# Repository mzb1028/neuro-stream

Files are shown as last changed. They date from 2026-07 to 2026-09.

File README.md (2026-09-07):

# Neuro-Stream

**One machine. Ten ingredients. Every drink exact.**

Neuro-Stream is a countertop smart-cartridge dispenser for functional powders
and liquid formulas. It builds a personalized drink in about a minute: it
meters up to **4 ingredients per serving to ±2%** accuracy, dissolves them
in-line in water heated to **±2 °F**, and cleans itself overnight.

**Engineering program: complete — all 6 phases founder-signed (2026-07-10),
plus a buildable MVP pack (wiring, plumbing, part list, build order).**

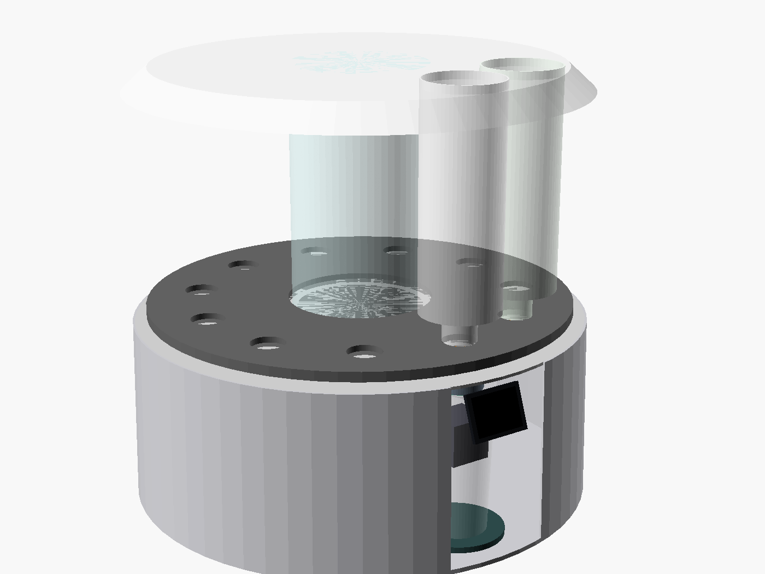
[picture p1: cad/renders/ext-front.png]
Neuro-Stream hero render


## How it works, in one paragraph

Eleven 1-liter smart cartridges (10 ingredients + 1 self-cleaning cartridge)
sit on a rotating carousel around a central removable ~3.5 L water tank. Each
cartridge contains its own factory-calibrated metering mechanism — a dosing
screw for powders, a piston pump for liquids in sterile no-preservative
bags — driven by a single shared motor through a standard docking interface.
Doses drop into a swirling stream of precisely heated water (a venturi
manifold with an off-center water inlet that spins the flow) and dissolve
in-line on the way to the glass. A built-in scale verifies every dose, an NFC
reader identifies each cartridge and loads its calibration, and an ESP32-S3
runs the touchscreen, app, auto-reorder, and wearable-driven recipe
suggestions — all fully usable with no phone present.

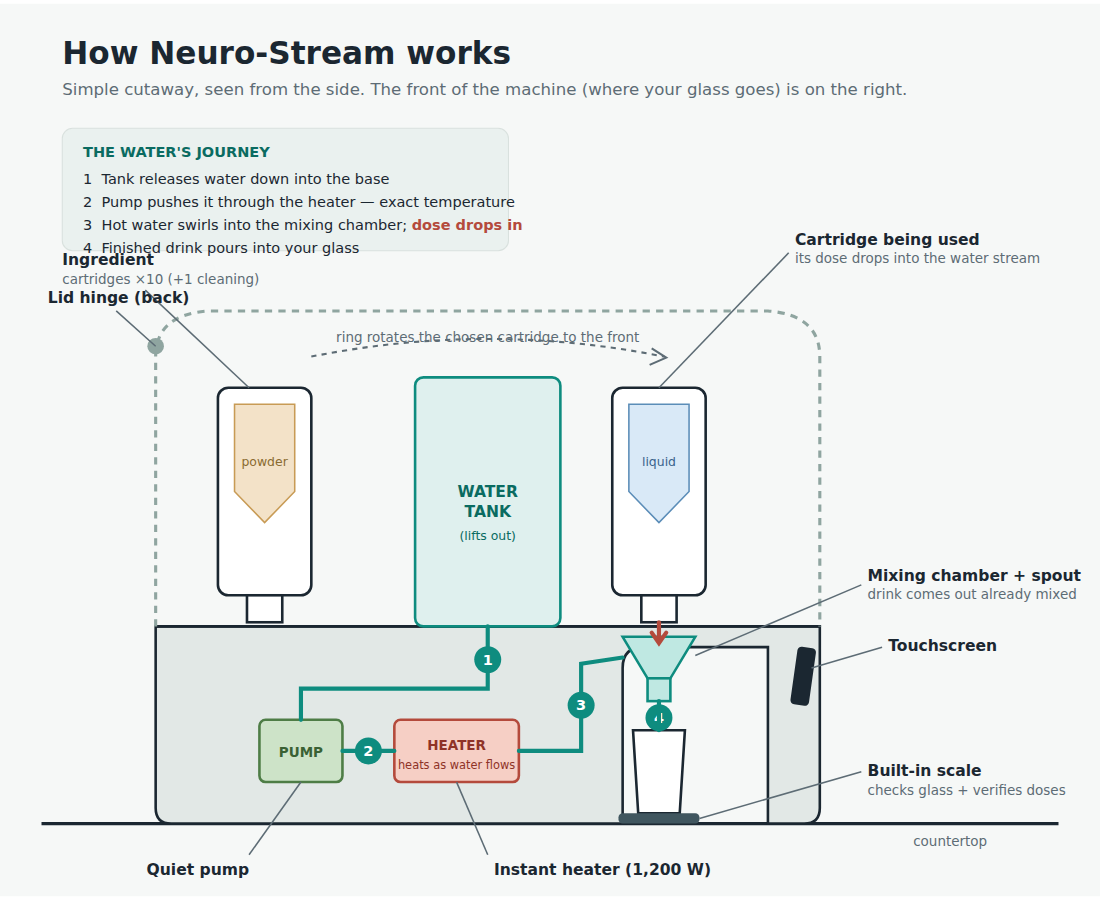
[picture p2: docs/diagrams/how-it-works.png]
How Neuro-Stream works — plain-language cutaway


## Key specs

| Spec | Value |
|---|---|
| Cartridge slots | 11 (10 ingredients + 1 cleaning) |
| Ingredients per drink | up to 4 |
| Dose accuracy | ±2% (scale-verified) |
| Water temperature | ±2 °F, per-recipe setpoint |
| Water tank | ~3.5 L, removable |
| Footprint | Ø 47 cm countertop |
| Controller | ESP32-S3, offline-first; app/NFC/wearables optional |
| Target retail | $499–549 at 5,000-unit production |

## Repository map

### Engineering documents (read in order)

| # | File | Contents |
|---|---|---|
| 1 | [docs/phase1-concept-and-mechanisms.md](docs/phase1-concept-and-mechanisms.md) | Mechanism trade study, dose envelope, architecture decision |
| 2 | [docs/phase2-cad.md](docs/phase2-cad.md) | Parametric CAD guide, tolerances, water/heating amendment |
| 3 | [docs/phase3-electronics-firmware.md](docs/phase3-electronics-firmware.md) | MCU, firmware design, thermal control, connected-product spec |
| 4 | [docs/phase4-materials-food-safety.md](docs/phase4-materials-food-safety.md) | FDA food-contact materials, certifications, self-cleaning model |
| 5 | [docs/phase5-manufacturing-dfm.md](docs/phase5-manufacturing-dfm.md) | DFM, tooling, costs from MVP ($55–105k) to 10k units ($139/unit) |
| 6 | [docs/phase6-validation-testing.md](docs/phase6-validation-testing.md) | Dosing/stability test protocols, certification checklist, stage gates |
| — | [docs/design-metering-venturi.md](docs/design-metering-venturi.md) | Deep dive: cartridge metering internals and wet-wall swirl manifold, with bench test plan |
| — | [docs/mvp-build-spec.md](docs/mvp-build-spec.md) | **Buildable MVP**: shopping list (~$700 electronics + ~$450 printed parts), ESP32 pin map, 4-stage build order, pass/fail tests |
| — | [docs/project-knowledge.md](docs/project-knowledge.md) | **Everything in one file** — self-contained program summary for sharing (Claude Project knowledge, data rooms, onboarding) |

### CAD (OpenSCAD, fully parametric)

| File | Contents |
|---|---|
| [cad/neuro-stream.scad](cad/neuro-stream.scad) | Complete machine: carousel, tank, base, hinged lid, touchscreen. `explode`, `cross_section`, `lid_open`, and `show_*` flags control views |
| [cad/cartridge-metering.scad](cad/cartridge-metering.scad) | Powder cartridge (hopper, sweeper, dosing screw, duckbill seal) and liquid cartridge (leadscrew piston, one-way valves) |
| [cad/venturi-manifold.scad](cad/venturi-manifold.scad) | Swirl mixing cone / venturi manifold |

Every dimension is a named variable. Renders of all views are in
[cad/renders/](cad/renders/).

### Presentation pages

| Where | Contents |
|---|---|
| [Live MVP Build Pack](https://claude.ai/code/artifact/5ff84554-1ebf-416a-b2bb-9e4c18771d7c) | Shareable web version of the build pack (private until shared from its menu) |
| [docs/mvp-build-pack.html](docs/mvp-build-pack.html) | The same page, archived in-repo — open locally in any browser |

### Schematics & diagrams

| File | Contents |
|---|---|
| [docs/diagrams/mvp-wiring.png](docs/diagrams/mvp-wiring.png) | Every wire and ESP32 pin, color-coded by voltage zone, with the full safety chain (GFCI → thermal fuses → relay → hardware watchdog) |
| [docs/diagrams/mvp-plumbing.png](docs/diagrams/mvp-plumbing.png) | Tank → check valve → pump → flow meter → heater → swirl cone, with tube lengths and fittings |
| [docs/diagrams/how-it-works.png](docs/diagrams/how-it-works.png) | Plain-language cutaway of the whole machine |

SVG sources sit next to each PNG.

## The MVP (start here to build)

The MVP in [docs/mvp-build-spec.md](docs/mvp-build-spec.md) is deliberately
**one dispense station with hand-swapped cartridges** — the rotating 11-slot
ring is proven engineering that would only add prototype cost without
reducing risk. The build proves the four claims nobody can prove on paper,
in risk order:

1. **Dry powder dosing** — no water, no mains; proves ±2% by itself
2. **Cold water + swirl cone** — proves in-line dissolution
3. **Smart tags** — NFC cartridge identity and calibration
4. **Heat, last** — only after the full safety chain is wired

Three of the four stages need no mains wiring at all. Every dispense logs a
CSV row; those logs are the evidence file for the beta gate and investors.

## Approved commercialization path

**MVP ($55–105k) → 150-unit beta (~$220k) → 1,000–1,500 soft-mold run →
steel tooling + 5,000-unit production (~$499–549 retail).**

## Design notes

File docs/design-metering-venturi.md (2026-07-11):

# Deep Design: Cartridge Metering Internals & Mixing Manifold

**Models:** [`cad/cartridge-metering.scad`](../cad/cartridge-metering.scad) ·
[`cad/venturi-manifold.scad`](../cad/venturi-manifold.scad)
**Status:** Prototype-ready — these are the two subsystems to build and test
first (they carry the ±2% dosing promise and the "dissolves properly" promise).
**Date:** 2026-07-10

---

## 1. Powder dosing screw — the details that make ±2% real

The screw geometry is easy; **dose consistency** is the design problem. Four
features do the work:

1. **Three confined flights.** The metering zone holds 3 full screw turns
   inside a tight barrel (Ø16 bore, molded to ±0.05 mm). Powder in this zone
   is fully enclosed — only the state of the last flight varies from serving
   to serving, so variance stays small even when the powder itself varies.
2. **Agitator sweeps the barrel entry at constant height.** Two arms turn
   with the screw, 2 mm above the entry slot, keeping it flooded with powder
   at constant pressure ("constant head") from a full cartridge to a nearly
   empty one. This is the anti-drift feature — without it, dose/rev falls as
   the powder column above gets lighter.
3. **60° hopper cone.** Steeper than any target powder's angle of repose plus
   margin → mass flow, no rat-holes, no dead powder at end of life
   (target residual <2% of fill).
4. **Suck-back finish.** At end of dose, firmware reverses the screw ½ turn to
   decompress the last flight, then the silicone duckbill closes. No dribble,
   no dose tail.

**The numbers:** ~1.09 cm³/rev → ~0.65 g/rev at 0.6 g/cm³ bulk density;
motor resolution 0.65 mg/step; 5 g serving ≈ 7.7 rev ≈ 5 s. Torque worst-case
(caked cohesive powder) ≈ 0.12 N·m vs. 2 N·m available — 16× margin, and the
drive current limit doubles as the jam detector.

**Accuracy budget (why ±2% closes):** bore molding ±0.05 mm → ±0.6% volume;
fill-fraction serving-to-serving σ ≈ 0.5–0.8% with the agitator (literature +
to be confirmed on rig); lash <0.1%; balance-verified calibration removes the
mean. Root-sum-square ≈ ±1.2–1.6% (3σ) — inside spec with margin.

## 2. Syrup piston pump — the risky bit is re-priming, not dosing

Dosing is geometric and boring (that's good): Ø20 bore × 4 mm lead = 1.26
mL/rev; bore tolerance ±0.05 mm → ±0.5% volume. The engineering risk is
**refilling the bore with 20,000 cP syrup** between strokes:

- Doses >12.6 mL need multiple strokes: dispense → retract (inlet umbrella
  valve opens, collapsible bag feeds the bore) → dispense again.
- Worst case (cold, thickest syrup): refill through the Ø8 inlet takes 4–7 s
  per stroke. Firmware paces retract speed using the viscosity class from the
  cartridge tag. A 30 mL thick-syrup serving ≈ 40–50 s — acceptable, but
  **this is the number the prototype must confirm.** Fallback knobs: Ø10
  inlet, dual inlet ports, or a lightly spring-loaded bag shell.
- Anti-drip: outlet duckbill needs 0.15 bar to open (holds the column), and a
  ¼-turn reverse decompresses the bore at end of dose.
- Piston seal: silicone X-ring (quad-ring) — lower friction than an O-ring,
  runs dry against a polished POM bore, no lubricant anywhere in the product path.

## 3. Mixing manifold — an honest design evolution

Testing the physics on paper changed the concept, and you should know why:
at our flow rate (~0.5 L/min) a classic venturi generates only ~100–400 Pa of
suction — **too weak to pull powder in reliably.** What works at this scale —
and what fountain and powder-drink machines actually use — is a **wet-wall
swirl cone**, which the model now implements:

- Water enters **tangentially** at the rim and spins into a thin film coating
  the whole cone wall. Powder falls from the cartridge outlet onto this
  *moving* film — every particle lands on water that's already flowing, so it
  wets instantly and can't clump or stick to a dry wall.
- The film converges into a Ø7 **throat** (the venturi-like element) where
  shear finishes dissolution, then a short **mixing tube** (3× throat
  diameter) evens concentration before the spout.
- **Vapor shield:** the subtle killer in hot-water powder systems is steam —
  it rises, condenses in the powder chute, and cakes it shut. A molded baffle
  ring keeps the drop path dry, with a drip edge so condensate returns to the
  swirl, never the chute.
- Still a twist-lock (3-lug bayonet), still the only user-washed part, still
  dishwasher-safe Tritan in production — prototype in clear SLA so you can
  *watch* the film form.

**Tuning knobs left deliberately parametric:** `throat_d` (5–9 mm),
`cone_angle` (50–65°), `inlet_d` (4.5–6 mm). These three get swept on the rig.

## 4. Bench prototype plan (~$2,500 total, 3–4 weeks)

**Rig A — dosing (from cartridge-metering.scad):** printed housings (clear
SLA) + MJF or machined-POM screws, NEMA17 + TMC2209 + ESP32 devkit, 0.001 g
balance. Cartridge hangs neck-down over the balance, exactly like the machine.

| Test | Method | Pass |
|---|---|---|
| Dose repeatability | 50 doses × {1, 5, 15 g} × {creatine, greens, maltodextrin} | σ ≤ 0.8% of dose |
| Life drift | Full-to-empty run, dose every 10th serving weighed | slope flat, all within ±2% of calibrated mean |
| Humidity abuse | Cartridge open at 32 °C/80 %RH for 48 h, then dose | within ±2%, no caking at wiper |
| Suck-back | High-speed video of outlet at dose end | 0 visible dribble |
| Syrup re-prime | 20k cP glycerin blend, cold (15 °C), full-stroke cycling | refill ≤7 s/stroke, dose σ ≤0.5% |
| Jam behavior | Deliberately caked plug | StallGuard trips before spline/screw damage |

**Rig B — mixing (from venturi-manifold.scad):** pump + bench heater + flow
meter into the tangential inlet; Rig A drops powder through the vapor shield.

| Test | Method | Pass |
|---|---|---|
| Film coverage | Dye pulse, clear body | full wet wall <1 s after flow start |
| Dissolution | 5 g greens into 250 mL at 20° and 60 °C; filter, dry, weigh residue | <1% undissolved; no wall cake after 20 servings, no manual clean |
| Steam/caking | 95 °C water 30 s, then powder drop; paper indicator in chute | chute bone dry |
| Carryover | Flavor A → 20 mL rinse → clean water; refractometer + taste | below taste threshold |
| Drip | Valve close, observe spout | ≤2 drops |

**Order of work:** print Rig A parts week 1; dose matrix weeks 2–3; Rig B
sweep (`throat_d` × `cone_angle` × `inlet_d`, ~12 printed variants at ~$18
each) weeks 2–4 in parallel. Every number that passes gets locked into the
main parametric model; every miss has its named fallback above.

These two rigs *are* the heart of the bench MVP from Phase 5 — passing this
plan means the four risky claims are two-thirds proven before the full
machine exists.

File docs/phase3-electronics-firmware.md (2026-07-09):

# Neuro-Stream — Phase 3: Electronics & Firmware

**Status:** Draft for founder sign-off
**Date:** 2026-07-09
**Scope:** dose control, thermal control (±2 °F), calibration, error handling,
power architecture, electronics BOM.

---

## 1. Microcontroller recommendation

**Primary: ESP32-S3-WROOM-1 module (Espressif) — ~$2.60 @ 5k, multi-source
distribution (Digi-Key/Mouser/LCSC), mature toolchain (ESP-IDF).**

Why it wins for this product:

- **Wi-Fi + BLE built in.** A $300–600 wellness appliance with per-user dose
  profiles, recipes, cartridge subscriptions, and OTA firmware updates needs an
  app. On any non-wireless MCU you'd add a radio module and end up paying more.
- **Horsepower headroom:** dual-core 240 MHz — one core owns hard-real-time
  control (steppers, PID, safety), the other runs UI/network. 512 KB SRAM +
  8 MB flash swallows the display UI and OTA A/B partitions.
- Peripherals cover the whole sensor set natively (I²C ×2, SPI, UART, PWM/MCPWM
  for steppers, ADC for NTCs, pulse counter for the flow meter, capacitive touch).
- Supply-chain: ESP32-S3 ships from multiple assembly houses; no allocation
  drama at 10k/yr volumes.

Alternatives considered: **STM32G0B1** (~$1.80) — cheaper, excellent control
MCU, but zero radio: adding BLE/Wi-Fi costs +$2.50–4 and a second firmware
target. **RP2040/RP2350** — nice PIO for steppers, but external flash + radio
still needed. **Nordic nRF52840** — BLE only (no Wi-Fi OTA/cloud), pricier.
Recommendation stands: one ESP32-S3 does everything.

**Safety split:** the 1200 W heater gets an independent hardware safety net
that works even if firmware crashes — two thermal cutoffs (one resettable
klixon, one one-shot fuse) in series with the heater line, plus a watchdog-fed
enable line: the TRIAC can only conduct while the MCU strokes a hardware
watchdog. This is the standard UL-friendly pattern.

## 2. Electronics architecture

```
                 ┌──────────────────────────────────────────────┐
                 │                ESP32-S3 module                │
                 │  core0: control loop (1 kHz)   core1: UI/net  │
                 └──┬─────┬─────┬─────┬─────┬─────┬─────┬───────┘
        TMC2209 ◄───┘     │     │     │     │     │     └──► 2.8" IPS touch (SPI)
      drive stepper   TMC2209   │     │     │     └──► NFC reader PN7150 (I²C)
      (NEMA17 1:5)    carousel  │     │     └──► HX717 load cell ADC
                      stepper   │     └──► flow meter (pulse counter)
                                └──► heater TRIAC (zero-cross, PWM burst)
                                     + 2× NTC (spout, heater body) via ADC
   Power: universal-input 12 V/5 A SMPS board (logic, motors, pump)
          + direct mains leg to heater through TRIAC + dual thermal cutoffs
```

Stepper drivers are **TMC2209**: silent (a kitchen product must not buzz) and
their **StallGuard load measurement is the jam sensor** — no extra hardware.

## 3. Firmware design

### 3.1 Dispense state machine (per recipe of up to 4 ingredients)

```
IDLE → CUP_CHECK → PREHEAT → for each ingredient i (≤4):
        INDEX(i) → DOCK → TAG_VERIFY → CO_DISPENSE(i) → UNDOCK
      → FLUSH → DONE  (any fault → SAFE_STOP → user message)
```

- `CUP_CHECK`: load cell confirms a vessel is present and tares it. No cup,
  no dispense — ever.
- `PREHEAT`: heater brings the loop to set-point ±2 °F before any product
  moves (see 3.3); water recirculates to drain volume is minimal (<15 mL).
- `CO_DISPENSE`: water flows through the venturi *while* the cartridge screw/
  piston meters product into the stream — dissolution happens in-line. Water
  volume per ingredient = recipe water ÷ ingredients, so the last mL of water
  always runs clean (self-rinsing spout).
- `TAG_VERIFY`: NFC tag must authenticate (signed), be in-date, and its
  remaining-dose counter must cover the request. Tag unreadable → **refuse to
  dispense, never guess.**
- `FLUSH`: 20 mL of clean hot water through the venturi at cycle end keeps the
  shared manifold rinsed after every serving.

### 3.2 Dose control (per ingredient)

```c
// dose_g  : target dose from recipe (clamped to tag's max_dose)
// k_cal   : g per drive revolution — read from THIS cartridge's NFC tag,
//           measured on the filling line for this lot (Phase 1, Arch. B)
revs      = dose_g / k_cal;
steps     = revs * STEPS_PER_REV * GEAR_RATIO;        // 0.65 mg/step resolution
run_stepper(DRIVE, steps, profile=TRAPEZOID);
// verification layer (doses ≥ 5 g): compare load-cell delta vs. target
delta = loadcell_delta();
if (dose_g >= 5.0 && fabs(delta - dose_g) > 0.04 * dose_g)   // 2× spec band
    raise(FAULT_DOSE_VERIFY, ingredient);
nfc_decrement_counter(dose_g);                        // update tag bookkeeping
```

### 3.3 Thermal control — hitting ±2 °F (±1.1 °C) at the spout

Classic PID is not enough on a flow-through heater; the loop uses
**feed-forward + PID trim**:

```c
// Feed-forward: power needed to lift measured flow to set-point
//   P_ff [W] = flow [g/s] × 4.186 [J/g°C] × (T_set − T_tank) [°C]
// PID trims the residual using the spout NTC (placed 20 mm after heater exit)
P = P_ff(flow, T_tank, T_set) + PID(T_set − T_spout);
triac_burst_set(P / P_MAX);          // zero-cross burst control, 50/60 Hz safe
```

- Pump runs at constant, flow-meter-verified rate → the feed-forward term is
  accurate, and PID only corrects ±3–4 °F of residual → settles inside ±2 °F
  in <4 s and holds it. This is proven Keurig/espresso-class control.
- **Cup compensation (UX):** optional "temperature at first sip" mode adds a
  model-based offset for vessel heat-steal, calibrated once per cup type.
- Guards: `T_heater_body > 260 °F` → hard fault; flow < 2 g/s while heating
  → boil-dry fault (pump lost prime / tank empty); both independent of the
  hardware cutoffs.

### 3.4 Calibration routines

- **Factory (per cartridge lot):** the fill line dispenses 3 test shots into a
  check-weigher and writes `k_cal` to the tag. The machine itself needs no
  per-cartridge calibration — it inherits it from the tag.
- **Machine self-check (monthly, automatic):** dispense 3 × 10 g water pulses
  by flow meter onto the load cell; cross-compare flow meter, load cell, and
  time. Any pair disagreeing >1.5% flags the drifting sensor and schedules a
  service prompt. This keeps the *verification* chain honest without user labor.
- **Load-cell zero:** auto-tare before every serving; creep-compensated.

### 3.5 Error handling matrix

| Fault | Detection | Response |
|---|---|---|
| Cartridge jam / powder bridge | TMC2209 StallGuard threshold + missed dose on load cell | Reverse ¼ turn ×3 (declog wiggle), retry once; else abort serving, message "Cartridge 4 jammed — remove and shake" |
| Low reservoir (cartridge) | NFC remaining-dose counter + StallGuard running-light signature | Warn at ≤3 servings; refuse when insufficient for recipe |
| Water tank empty | Flow < 2 g/s with pump on | Pause serving, prompt refill, resume (recipe state preserved) |
| Dose verify miss (≥5 g) | Load-cell delta outside ±4% | Abort remaining recipe, flag cartridge, log for QA |
| Overtemp | Spout or body NTC over limit | Firmware kills TRIAC; hardware cutoffs back-stop |
| NFC unreadable/invalid | Auth fail / CRC fail | Refuse that cartridge only; rest of carousel usable |
| Carousel mis-index | Dock cone hall sensor absent after index | Re-home carousel (one full revolution), retry once |
| MCU hang | Hardware watchdog | Heater + motors drop out in <100 ms |

## 4. Battery vs. mains — decided by physics

The 1200 W heater ends this debate: heating 300 mL from 68→140 °F takes
~50 kJ ≈ a **full 18650 cell per drink**. Battery operation would need a
laptop-pack-sized battery per day of use. **v1 is mains-only (universal
100–240 V input).** The only battery aboard is a coin cell for the RTC so
schedules survive unplugging. (A future battery "travel dispenser" would be a
no-heat, dose-only device — different product.)

## 5. Electronics BOM estimate (5k units, mid-2026 pricing)

| Item | Qty | Est. unit cost |
|---|---|---|
| ESP32-S3-WROOM-1 (8 MB) | 1 | $2.60 |
| TMC2209 driver | 2 | $1.40 ea |
| NEMA17 stepper + 1:5 planetary (drive) | 1 | $9.50 |
| NEMA17 pancake stepper (carousel) | 1 | $5.50 |
| Load cell 1 kg + HX717 ADC | 1 | $2.80 |
| NFC reader PN7150 + antenna | 1 | $2.90 |
| 2.8" IPS touch display (SPI) | 1 | $8.00 |
| Diaphragm pump (flow-controlled) | 1 | $8.00 |
| Inline thick-film heater 1200 W | 1 | $14.00 |
| Flow meter (hall) | 1 | $2.50 |
| NTC sensors ×3, thermal cutoffs ×2 | — | $3.20 |
| TRIAC + zero-cross + snubber | 1 | $2.20 |
| 12 V/5 A universal SMPS board | 1 | $6.50 |
| Main PCB (4-layer) + passives + connectors | 1 | $7.50 |
| Wiring harness, dock hall sensor, misc | — | $5.00 |
| **Electronics + electromechanical subtotal** | | **≈ $83** |

(Machine-total BOM including mechanics/enclosure lands in Phase 5; this
subtotal is consistent with a $400–700 retail device at standard multipliers.)

---

**✅ SIGNED OFF by founder (2026-07-09), with amendments:**
1. ESP32-S3 — **approved**, with expanded connected-product requirements (§6)
2. Mains-only — **approved**
3. Error-handling matrix — **approved**, plus offline-first requirement (§6.3)
4. Touchscreen — **approved** (2.8" IPS capacitive)

## 6. AMENDMENT — Connected-product requirements (founder, 2026-07-09)

### 6.1 Auto-reorder
The NFC dose counter already gives per-cartridge remaining servings. Cloud
service adds: low-cartridge event at ≤3 servings → touchscreen + push prompt
("Running low on <name> — reorder?") → one-tap confirm against the stored
subscription. Fully hardware-free; requires the commerce backend (flagged as
a software-team deliverable, not in device BOM).

### 6.2 Wearable integration
Architecture: the **phone app** is the health-data bridge — it reads Apple
HealthKit / Google Health Connect / Garmin / Whoop / Oura APIs and computes
recipe suggestions (e.g., post-run → electrolyte-forward blend, hydration
deficit → larger water volume), which sync to the machine over Wi-Fi/BLE.
The machine itself never talks to wearables directly (no watch vendor allows
third-party devices as direct peers; the phone-bridge is the standard and
correct pattern). No hardware impact; ESP32-S3 BLE also enables direct
phone-to-machine control when offline.

**Regulatory guardrail (carries into Phases 4/6):** health-data-driven dosing
must be presented as *wellness suggestions the user confirms*, never as
automatic therapeutic dosing — otherwise the product risks classification as
a medical device (FDA SaMD). UX copy and marketing must respect this line.

### 6.3 Offline-first (no phone nearby)
The touchscreen is a full-fidelity controller: profiles, saved recipes,
manual dose/temperature/volume, cartridge status, and error recovery all work
with no phone and no internet. Cloud features degrade gracefully (reorder
prompts queue; wearable suggestions simply absent). Firmware rule: **no
dispense path may ever require network round-trips.**

**→ Phase 4: materials & food-safety compliance** (see `docs/phase4-materials-food-safety.md`)

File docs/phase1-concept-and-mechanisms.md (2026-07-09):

# Neuro-Stream — Phase 1: Concept & Mechanism Logic

**Status:** Draft for founder sign-off
**Date:** 2026-07-08

---

## 1. Design inputs (as agreed, with gaps filled by stated assumptions)

| Parameter | Value | Source |
|---|---|---|
| Use context | Consumer countertop, home/on-the-go, zero technical skill | Founder |
| Dosing accuracy | ±2% of target dose per serving | Founder |
| Formula forms | **Both dry powder and liquid**, varying per cartridge | Founder |
| Cartridge count | **Up to 10 independent cartridges**, shipped to user pre-filled | Founder |
| Cartridge capacity | Up to 1 L (or 1 kg-class for powder) each | Founder |
| Dose per serving | Varies by ingredient — see proposed dose envelope (§2) | Founder ("depends") |
| Storage/refrigeration | Unknown — recommendation in §3 | Founder ("advise me") |

> Founder supplied three AI-generated concept renders (rough intent only, not a
> final design). They are reconciled against this phase in **§6**.

### 1.1 What "up to 10 cartridges, powder AND liquid" forces on the design

1. **You cannot afford 10 machine-side precision mechanisms.** Ten motors, ten
   pumps, ten cleanable food-contact paths is a $600+ BOM and a sanitation
   nightmare. Every credible multi-ingredient consumer machine (Keurig,
   Bartesian, Cana) solves this by putting the food-contact complexity in the
   **disposable/replaceable cartridge** and keeping one shared drive in the machine.
2. **Powder and liquid need different metering physics.** No single mechanism
   meters both a cohesive powder and a 5,000 cP syrup at ±2%. The system must
   either (a) run two parallel subsystems, or (b) make the *cartridge* carry the
   media-specific metering element behind a *common mechanical interface*.
3. **±2% across varying particle sizes and viscosities** rules out any open-loop
   mechanism whose delivery-per-actuation depends on the bulk properties of the
   formula — unless each cartridge is factory-calibrated for its specific fill.

## 2. Proposed dose envelope (needs your confirmation)

Since dose "depends on what is being dosed," the machine must be specified
against an envelope. Proposed ingredient classes:

| Class | Form | Dose range | ±2% means | Notes |
|---|---|---|---|---|
| P1 — micro powder | Powder | 0.25–2 g | ±5–40 mg | Concentrated actives (e.g., caffeine blends **pre-diluted in carrier** — see safety note) |
| P2 — standard powder | Powder | 2–15 g | ±40–300 mg | Typical nootropic/greens/creatine-class servings |
| L1 — thin liquid | Liquid | 0.5–10 mL | ±10–200 µL | Tinctures, flavor/active concentrates, ≤ ~500 cP |
| L2 — syrup | Liquid | 5–50 mL | ±0.1–1 mL | Sweetener/functional syrups, up to ~20,000 cP |

**Formula limits the device will impose** (state these to your formulator):

- **Powders:** moisture < 5%, free-flowing to moderately cohesive
  (Carr index ≤ ~25 preferred), particle size D50 ≈ 100–800 µm, oil/fat
  content < ~5% (sticky powders bridge and smear). Hygroscopic powders
  allowed only with desiccant cartridge + wiper-sealed outlet.
- **Liquids:** 1–20,000 cP at 20 °C, no particulates > 0.5 mm, no
  carbonation, must tolerate the cartridge's in-use life at ambient.
- **Safety-by-formulation:** any active where a 2× overdose is harmful must be
  diluted in carrier so that a full-mechanism-fault dose is still safe.
  A consumer device cannot be the sole overdose safeguard.

## 3. Refrigeration & environmental protection — recommendation

**Recommend: design the machine ambient-only and make shelf stability a
formulation/cartridge requirement, not a device feature.**

- Onboard refrigeration (thermoelectric or compressor) adds roughly $40–80 BOM,
  ~2–4 L of enclosure volume, continuous 30–60 W draw (kills any battery
  option), condensation management inside a powder machine (bad), and drives
  you toward compressor reliability/warranty issues. Cana's cooled multi-liquid
  machine ended up at a ~$500–900 price point partly for this reason.
- Instead, protect the formula **in the cartridge**:
  - **Powder cartridges:** integrated desiccant chamber, foil induction seal
    pierced at install, elastomer wiper seal on the outlet so ambient humidity
    can't wick up the dispense path between doses.
  - **Liquid cartridges:** collapsible inner bag (bag-in-shell) so no air
    headspace forms as it empties — this addresses oxidation without nitrogen
    hardware; opaque shell handles light sensitivity.
  - **In-use life** (time from install to empty) becomes a cartridge spec, e.g.
    30–60 days at 15–30 °C / ≤ 60% RH. Your formulator validates each formula
    against it (Phase 6 has the test protocol).
- If a future formula genuinely requires cold chain, that becomes a v2 chilled
  bay variant — don't tax every unit for it.

---

## 4. Three mechanism architectures

### Architecture A — Machine-side dedicated mechanisms per media type
*(bank of mini-augers for powder slots + peristaltic pumps for liquid slots)*

Cartridges are dumb containers; the machine owns all metering. Powder slots get
a stainless auger + agitator each; liquid slots get a peristaltic pump each
(tubing is the only food-contact pump part). A slot is factory-configured or
user-configured as powder or liquid.

**Dosing accuracy path:** auger dose = flights × fill fraction; step-count the
motor. Fill fraction varies with powder cohesion, humidity, and fill level →
open-loop auger accuracy is realistically ±3–8% for varying powders; hitting
±2% requires per-formula calibration *and* stable powder properties, or weight
feedback. Peristaltic is ±1–2% when tubing is fresh but drifts 5–10% as tubing
takes compression set over weeks.

**Pros for your formula set**
- Handles both media with proven, well-understood mechanisms.
- Cartridges are cheap dumb bottles → lowest recurring cost per fill.
- Peristaltic keeps liquid inside disposable tubing — decent hygiene story for liquids.

**Cons**
- **10 mechanisms:** even with clever clutching, this is the highest machine BOM
  and part count of the three.
- Powder path (auger, chute) is machine-side food contact → user must
  disassemble and wash 10 metering assemblies; cross-contamination between
  refills; allergen carryover risk.
- Auger accuracy on *varying* powders won't reliably hit ±2% open-loop.
- Peristaltic tubing is a wear item the consumer must replace on schedule.

**Rough part count / complexity:** ~10 motors (or 1–2 motors + 10-way clutch,
which is its own complexity), ~25–35 parts per powder slot, ~15–20 per liquid
slot → **300+ parts total**, high.

**Food-contact materials:** 316/304 SS or acetal (POM) augers, PP/Tritan
hoppers, platinum-cured silicone peristaltic tubing (all 21 CFR 177-coverable —
detail in Phase 4).

**Failure modes:** powder bridging/rat-holing in hoppers; auger clogging with
hygroscopic caking; peristaltic tube fatigue → drift then rupture; humidity
ingress into open machine-side powder path; cleaning non-compliance by users
(the biggest real-world failure).

---

### Architecture B — Smart cartridges with integrated positive-displacement
metering + one shared machine drive **(recommended)**

Each cartridge contains its own media-matched metering element behind a
**standardized drive interface** (a spline/dog-clutch socket in the cartridge
base). The machine has **one** drive motor that reaches each cartridge —
either the cartridges sit on a rotating carousel over a fixed drive/dispense
station, or a small gantry carries the drive head across a fixed cartridge rack
(decided in Phase 2 against your sketch).

- **Powder cartridge:** molded auger/dosing-screw integral to the cartridge,
  with a slow agitator flight above it (same shaft), foil seal, outlet wiper.
- **Thin-liquid cartridge:** miniature piston/diaphragm dosing element or
  rotary dosing valve, fed by the collapsible bag.
- **Syrup cartridge:** progressive-cavity or larger-bore piston element (the
  interface torque budget is sized for worst-case viscosity).
- Each cartridge carries an **NFC/QR tag** with: ingredient ID, lot,
  **factory-measured calibration constant (g or mL per drive revolution for
  that exact fill lot)**, max dose per serving, expiry, doses-dispensed counter.

**Dosing accuracy path:** positive displacement + per-lot factory calibration
removes the "properties vary" problem — the calibration constant is measured
*with the actual formula in the actual cartridge design* at fill time. Motor
step-counting delivers the dose. Because the metering element is **new with
every cartridge**, wear-related drift resets every ~1 L. Expected: ±2–3%
open-loop; ±2% is met by (a) tightening cartridge molding tolerances on the
metering chamber, and (b) the gravimetric trim described in §5. Fill-level
dependence is handled by the agitator (powder) and collapsed bag (liquid).

**Pros**
- **One motor, near-zero machine-side food contact.** The user never cleans a
  metering mechanism — they recycle it with the cartridge. This is the only
  architecture where "no technical knowledge required" survives contact with
  10 ingredients.
- Cross-contamination and allergen carryover structurally eliminated (each
  formula's entire wetted path is its own cartridge; only the last ~10 mm of
  drop path is shared and is a removable, dishwasher-safe funnel).
- Powder vs. liquid is solved per-cartridge-SKU, invisible to the machine.
- Per-lot calibration is a genuinely strong accuracy story for a formula whose
  particle size and viscosity vary batch to batch.
- Business model alignment: cartridges are already being shipped to users.

**Cons**
- Cartridge unit cost carries the mechanism: roughly **$0.40–1.20 added COGS
  per cartridge** at volume (molded auger or piston element + seals + tag).
- Requires real injection-mold tooling investment for 2–3 cartridge variants
  before revenue (mitigate: launch with powder + one liquid variant).
- Filling line must include a calibration/check-weigh station.
- Drive interface (spline + docking) needs careful tolerance work — it's the
  one precision machine-side part.

**Rough part count / complexity:** machine ≈ **60–90 parts** (1 drive motor +
gearbox, carousel or gantry with 1–2 cheap positioning motors, load cell,
electronics, enclosure); cartridge ≈ 6–9 parts each (shell, bag or agitator,
metering element, seals, foil, tag, cap). Medium overall — complexity is
shifted into high-volume molded disposables, which is where manufacturing is
cheapest.

**Food-contact materials:** cartridge shell PP or PET, metering screw/piston
POM or PP, seals platinum-cured silicone or TPE, bag PE/EVOH laminate — all
mainstream 21 CFR 177 materials (Phase 4).

**Failure modes:** powder caking if user stores machine in high humidity
(mitigated by desiccant + wiper seal); mold-to-mold variation in metering
chamber volume (mitigated by per-lot calibration, which absorbs it); drive
spline wear (machine side, hard-anodized or SS, 10k-cycle rated); counterfeit
or refilled cartridges dosing wrongly (mitigated by signed NFC tags); tag
read failure (fail-safe: refuse to dispense, never guess).

---

### Architecture C — Gravimetric closed-loop
*(crude dispense mechanisms + precision load cell; accuracy from measurement,
not metering)*

Any cheap dispense method (coarse auger, pinch valve on gravity-fed liquid)
runs in closed loop against a load cell under the user's glass: dispense fast
to ~90% of target, then pulse in dribble mode until the scale reads the target.

**Dosing accuracy path:** accuracy = scale accuracy. A consumer-grade load
cell + 24-bit ADC (HX711-class) realistically holds ±0.1 g in a kitchen
environment (vibration, thermal drift, someone bumping the counter).
**±2% is therefore only achievable for doses ≥ ~5 g.** Class P1 (0.25–2 g)
and L1 low-end (0.5 mL) fail the spec outright. Liquids also drip/string after
cutoff, corrupting the endpoint.

**Pros**
- Totally agnostic to formula changes — no per-lot calibration, self-corrects
  bridging and partial clogs, inherently detects jams and empty cartridges.
- Cheapest cartridges of the three (dumb containers).
- The load cell doubles as a UX feature ("add 200 mL water… done").

**Cons**
- **Cannot meet ±2% below ~5 g** → fails your micro-dose classes.
- Slow: dribble-mode endpoint approach adds 5–20 s per ingredient × up to 10
  ingredients per drink.
- Requires the user's vessel on the scale, correctly placed, undisturbed —
  fragile against exactly the "no technical knowledge" user you're targeting.
- Still needs 10 crude dispensers with machine-side food contact (Architecture
  A's cleaning problem returns, just with cheaper mechanisms).

**Rough part count / complexity:** ~200+ parts (10 crude dispensers + scale
station). Medium-high.

**Food-contact & failure modes:** as Architecture A for the dispense path;
plus load-cell drift, tare errors, vibration sensitivity, drip-after-cutoff.

---

## 5. Recommendation: Architecture B, with a load cell as a verification layer

**Primary metering: cartridge-integrated positive displacement (B).
Secondary: a load cell under the dispense station used not for control but for
*verification and drift/jam detection* on doses ≥ ~5 g (a de-contented C).**

Justification against the alternatives:

1. **Only B meets ±2% across the whole dose envelope.** C's physics caps it at
   ~5 g minimum. A's open-loop auger can't hold ±2% on powders whose particle
   size and cohesion vary — and your formula characteristics explicitly vary.
   B converts that variability from a machine problem into a fill-line
   calibration measurement, which is where you can actually control it.
2. **Only B survives the consumer-simplicity requirement at 10 ingredients.**
   A and C both leave 10 food-contact metering paths in the machine that a
   non-technical user must clean correctly, repeatedly, forever. Field data
   from every appliance category says they won't. B's user-facing sanitation
   burden is one dishwasher-safe drop funnel.
3. **Cost lands in the right place.** A puts ~$300+ of mechanisms in a machine
   you sell once (probably at a loss). B puts ~$1 of mechanism in a cartridge
   you sell every month — and injection-molded disposables at volume are the
   cheapest precision parts in existence.
4. **The load-cell layer buys back C's best property cheaply** (~$4 of BOM):
   every ≥5 g dose is check-weighed, so the machine detects clogs, exhausted
   cartridges, and calibration drift, logs accuracy for QA/regulatory
   evidence, and can flag "cartridge underdelivering — replace" instead of
   silently mis-dosing. Small doses rely on positive displacement + factory
   calibration alone, which is exactly where positive displacement is
   strongest.

**Cost of this choice, stated plainly:** upfront cartridge tooling
(~$80–250k across 2–3 cartridge variants before launch) and recurring
cartridge COGS. If that capital doesn't exist, the fallback is Architecture A
reduced to **3–4 slots** with a relaxed accuracy spec (±5%) on powders — but
that is a different product. Recommendation stands on B.

### Carry-forward decisions for Phase 2 (CAD)

- Carousel vs. gantry cartridge presentation — **decide against your sketch**
  (please attach it with your sign-off).
- Standard drive interface geometry (spline profile, docking float, torque cap).
- Cartridge variant set for launch: P2 powder + L2 syrup first; P1/L1 second.
- Shared drop-funnel geometry and its removal/cleaning gesture.

---

## 6. Reconciliation with founder's concept renders

The three renders (Gemini-generated, directional only) show:

1. **An under-counter, plumbed, pull-out-drawer appliance** integrated into
   cabinetry, with a dedicated counter-top tap/faucet, inline water-filter
   housings, and a touch control panel.
2. **Cartridges as inverted metal bottles** (6–8 visible) docked mouth-down in
   a drawer rack, with labels like "Sparkling Water / Cold Brew / Cucumber
   Lime / Still Water."
3. **A 12-position rack of small flavor pucks** plus what appears to be a
   **CO₂ cylinder** and filter canisters.

**What this confirms about Phase 1:**

- The fixed **rack + drawer** layout in the renders settles the carousel vs.
  gantry question in favor of **fixed cartridge rack** — either a traveling
  drive head (gantry) or, better for a drawer, **one small drive/valve module
  per docking station fed by a single shared controller** re-evaluated in
  Phase 2 against cost.
- Inverted bottle-style cartridges docking mouth-down onto a station is
  exactly Architecture B's smart-cartridge docking concept. The metering
  element lives in the bottle's neck/cap assembly.
- 10–12 positions matches the agreed "up to 10" envelope.

**What this changes / adds (scope decisions needed):**

| Render feature | Implication | Decision needed |
|---|---|---|
| Plumbed water line + tap | This is a **point-of-use water dispenser that doses formula into the water stream**, not a device dosing into an arbitrary glass. Dispense path becomes an inline injection manifold; the "drop funnel" becomes a tap spout. Installation now involves a plumber or a tank-fed fallback. | In or out for v1? Plumbed-in roughly doubles regulatory surface (NSF/ANSI 42/53/61 for the water path) and kills "on-the-go." |
| Under-counter drawer form factor | Sheet-metal chassis + drawer slides instead of a molded countertop enclosure; changes Phase 2 CAD entirely. Conflicts with the stated "countertop, on-the-go" use context. | Countertop v1 with the same cartridge/docking system, drawer version as v2? (Recommended — the cartridge platform is the asset; the enclosure can vary.) |
| CO₂ cylinder / sparkling | Carbonation module: regulator, carbonator, certified cylinder handling. Big, well-understood, but a product in itself. | Recommend **out of v1**; the docking rack design will not preclude adding it later. |
| Chilled water ("Cold Brew," temperature display) | Water chilling is different from formula refrigeration (§3 stands: cartridges stay ambient). A thermoelectric water chiller is feasible in a plumbed v2. | Defer with plumbing decision. |
| Metal bottle cartridges | Aluminum bottles are premium-looking but fight Architecture B: molded metering elements, NFC tags, and collapsible liners integrate far more cheaply into a **molded PP/PET shell** (which can be metallized or sleeved for the same look). | Treat metal look as industrial design finish, not construction. |

**Recommended v1 scope, restated:** countertop enclosure, 10-position fixed
rack of smart cartridges (Architecture B), doses into the user's own glass/
bottle of water via a short shared spout, load-cell verification underneath.
Plumbing, carbonation, and water chilling are v2 features the docking
architecture deliberately leaves room for.

---

**✅ SIGNED OFF by founder (2026-07-09), with amendments:**
1. Architecture B (+ load-cell verification) — **approved**
2. Dose envelope classes P1/P2/L1/L2 (§2) — **approved** (clarified: these are
   per-serving dispense ranges, not cartridge sizes; cartridges remain 1 L)
3. Ambient-only storage — **approved with condition: all ingredients are
   preservative-free.** Consequences adopted:
   - Powders: unaffected (dry + desiccant + foil seal is sufficient).
   - Liquids: **sterile-fill into a collapsible aseptic bag with a one-way
     check valve** is the mandatory packaging standard. In-use life per
     formula must be validated in Phase 6; thin aqueous liquids may carry a
     shorter machine-enforced expiry (read from the cartridge tag).
4. Launch cartridge set P2 powder + L2 syrup — **approved**
5. v1 scope (countertop, dose-into-glass; plumbed drawer = v2) — **approved**

**Added requirement (founder, 2026-07-09):** one serving may combine **up to
4 ingredients** (any mix of powders and liquids). Implemented as sequential
dispensing of up to 4 cartridges into the shared funnel per recipe. Whether
the machine also *stirs* the finished drink is flagged as an open industrial-
design decision in the Phase 2 document (recommendation: user stirs in v1).

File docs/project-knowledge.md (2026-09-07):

# Neuro-Stream — Complete Project Knowledge File

*Self-contained summary of the entire engineering program. Drop this file into
any workspace (Claude Project, Notion, investor data room) and the reader has
the whole picture. Full detail lives in the repo:
https://github.com/mzb1028/neuro-stream — status as of 2026-09-07.*

---

## 1. What Neuro-Stream is

A countertop smart-cartridge dispenser for functional powders and liquid
formulas. It builds a personalized drink in about a minute: meters up to
**4 ingredients per serving to ±2%** accuracy, dissolves them in-line in
water heated to **±2 °F** of the recipe setpoint, verifies every dose on a
built-in scale, and cleans itself overnight.

**Program status: complete.** All six engineering phases founder-signed
(final sign-off 2026-07-10), plus a hands-on MVP build pack (wiring,
plumbing, parts list, build order) added afterward.

### Key specs

| Spec | Value |
|---|---|
| Cartridge slots | 11 (10 ingredients + 1 self-cleaning cartridge) |
| Cartridge capacity | 1 L / ~1 kg-class each, shipped pre-filled |
| Ingredients per drink | up to 4 |
| Dose accuracy | ±2%, factory-calibrated per cartridge, scale-verified |
| Water temperature | ±2 °F (±1.1 °C) at the spout, per-recipe setpoint |
| Water tank | ~3.5 L, removable |
| Footprint | Ø 47 cm countertop |
| Controller | ESP32-S3; Wi-Fi/BLE, NFC, touchscreen; fully offline-capable |
| Power | Mains (1200 W inline heater rules out battery) |
| Target retail | $499–549 at 5,000-unit production |

## 2. The architecture (Phase 1 decision)

Three architectures were traded off:

- **A — machine-side mechanisms per media type**: rejected ($600+ BOM, 10
  cleanable food paths, sanitation nightmare).
- **B — smart cartridges with integrated positive displacement** ✅ chosen:
  each cartridge carries its own media-specific metering element (dosing
  screw for powders, piston pump for liquids in sterile no-preservative
  bag-in-box) behind a common docking interface, driven by ONE shared machine
  motor. Factory calibration per cartridge, stored on its NFC tag.
- **C — gravimetric closed-loop**: kept as a *verification* layer only — a
  load cell under the glass checks every dose rather than controlling it.

Why: no single mechanism meters both cohesive powder and 5,000 cP syrup to
±2%; putting food-contact complexity in the replaceable cartridge (the
Keurig/Bartesian/Cana pattern) keeps the machine clean and cheap.

**Dose envelope** the machine is specified against: P1 micro powders
0.25–2 g, P2 standard powders 2–15 g, L1 thin liquids 0.5–10 mL (≤500 cP),
L2 syrups 5–50 mL (≤20,000 cP). Concentrated actives must be pre-diluted in
carrier by the formulator.

## 3. Mechanical design (Phases 2 + deep dive)

- **Layout**: 11 cartridges on a rotating carousel around a central removable
  water tank; hinged clear lid; front dispense bay with touchscreen; drive
  motor, pump, heater, and PCBA in the base.
- **Powder cartridge internals**: hopper cone with rotating sweeper arms
  (prevents bridging/rat-holing), precision dosing screw, silicone duckbill
  outlet seal. Delivery is per-revolution, calibrated at fill time.
- **Liquid cartridge internals**: leadscrew-driven piston pulling from an
  aseptic bag (no preservatives needed), one-way valves; the engineering risk
  is re-priming after idle, not dosing.
- **Mixing**: doses drop dry into a venturi/swirl manifold; heated water
  enters the cone **tangentially (off-center)** so it spins — a straight-in
  inlet dribbles down one wall and clumps powder. Dissolution happens in the
  stream, not in the glass.
- **CAD**: fully parametric OpenSCAD — `cad/neuro-stream.scad` (whole
  machine, with `explode`/`cross_section`/`lid_open` flags),
  `cad/cartridge-metering.scad`, `cad/venturi-manifold.scad`. 20+ renders in
  `cad/renders/`.
- **One precision metal part**: the drive spline shaft, CNC 316L stainless
  (corrected from 303 during the materials review), ~$3.80/pc.

## 4. Electronics & firmware (Phase 3)

- **MCU**: ESP32-S3 (Wi-Fi + BLE on module). Drives: 2× stepper (TMC2209
  with StallGuard jam detection — cartridge drive + carousel), 12 V
  diaphragm pump (MOSFET), 1200 W inline heater via zero-cross SSR, flow
  meter, 2× NTC (spout tee + heater body), 1 kg load cell + HX717, PN532
  NFC at the dock collar, 2.8" IPS SPI touchscreen, hall/reed position
  switches.
- **Dispense state machine**: identify cartridge (NFC) → rotate to dock →
  dose (steps from stored calibration) → scale verification → next
  ingredient → heat/mix water pass → done. Error matrix covers jams
  (StallGuard), empty cartridge, no glass, boil-dry.
- **Thermal control**: feed-forward + PI on the spout NTC hits ±2 °F;
  firmware boil-dry guard (flow < 2 g/s → heater off) plus hardware chain:
  GFCI → 2 thermal cutoffs in series → SSR → hardware watchdog that kills
  heat if firmware hangs.
- **Connected product (founder amendment)**: auto-reorder from cartridge
  fill-level telemetry; wearable integration drives recipe *suggestions*
  (wellness framing, not medical); **offline-first** — every function works
  with no phone present.
- Electronics BOM ≈ $83/unit at 5k volume.

## 5. Materials & food safety (Phase 4)

- Cartridge wetted parts: Tritan shells, POM screw/piston, platinum-cured
  LSR seals/valves, aseptic PE bag — all FDA food-contact grades with
  supplier letters collected into an FDA food-contact file.
- Machine water path: Tritan tank and manifold, silicone tube, 316L wetted
  heater.
- **Self-cleaning model (founder-approved)**: slot 11 holds a cleaning
  cartridge; machine runs an overnight rinse/sanitize cycle through the
  full wet path. Design requirement: no dead legs, all wetted surfaces
  flushable.
- Certifications flagged: UL/ETL 60335-2-15 (mandatory — it heats water),
  FCC (module-based), FDA food-contact file, NSF/ANSI 42 (voluntary),
  CA Prop 65, 21 CFR 111 cGMP filling via co-packer.

## 6. Manufacturing & cost (Phase 5)

**Tooling (Asia)**: machine ≈ $180–225k, cartridges ≈ $117k → **program
total ≈ $300–340k** one-time (1.7–2× if tooled in the US). This is the
capital gate.

**Machine build cost / suggested retail** (±15% estimate grade):

| Year-1 volume | Build cost | Landed (+12%) | Retail (≈3×) |
|---|---|---|---|
| 2,000 | ≈ $188 | ≈ $211 | $599–649 |
| 5,000 | ≈ $158 | ≈ $177 | **$499–549** |
| 10,000 | ≈ $139 | ≈ $156 | $449–479 |

**Small batches (100–1,500 units)** skip steel tools: MJF/SLS-printed or
CNC enclosures at 100–500 units, soft aluminum molds at 500–1,500. The one
exception: **cartridge food-contact parts can never be 3D printed** — soft
cartridge molds (~$50–65k) are unavoidable even for a 100-unit pilot.
Aseptic bags come from a bag-in-box supplier (MOQ ~50k).

**Approved commercialization path**:
MVP ($55–105k) → 150-unit beta (~$220k) → 1,000–1,500 soft-mold run →
steel tooling + 5,000-unit production run.

## 7. Validation & certification (Phase 6)

- **Dosing protocol**: full-to-empty cartridge runs on the bench MVP,
  repeated on every design change; every dispense logs a CSV row — the logs
  are the evidence file for the beta gate and investors.
- **Temperature protocol**: spout-thermocouple verification across
  setpoints and tank temperatures.
- **150-unit beta adds** real-world variation: homes, water hardness, user
  abuse, formula stability in the machine.
- **Formula stability**: accelerated studies during beta, real-time before
  retail ($8–15k per formula).
- **Certification budget through retail: ≈ $90–150k** (UL $25–40k, FCC
  $5–10k, FDA file $8–15k, NSF $10–20k, legal reviews, product-liability
  insurance ~$15–30k/yr — required before even beta loaners ship).
- Stage gates: MVP must pass bench dosing + temperature before beta; beta
  must pass stability + formal certs before soft-mold run.

## 8. The MVP (buildable today)

Deliberately **one dispense station with hand-swapped cartridges** — the
rotating ring is proven engineering that adds prototype cost without
reducing risk. ~$1,150 in parts (~$700 electronics/hardware + ~$450 printed
parts), ~2 weekends of assembly.

Build order, risk-first:
1. **Dry powder dosing** — no water, no mains; alone proves ±2%
2. **Cold water + swirl cone** — proves in-line dissolution
3. **Smart tags** — NFC identity + calibration
4. **Heat, last** — only after the full hardware safety chain is wired

Three of four stages need no mains wiring; a pre-built inline heater or an
appliance tech can cover the fourth. Full parts list, ESP32 pin map,
assembly order, firmware starting points, and pass/fail criteria:
`docs/mvp-build-spec.md`. Every-wire schematic and every-tube plumbing
diagram: `docs/diagrams/mvp-wiring.png`, `docs/diagrams/mvp-plumbing.png`.

## 9. Where everything lives

| Asset | Location |
|---|---|
| Repository (single source of truth) | https://github.com/mzb1028/neuro-stream |
| Phase docs 1–6 | `docs/phase1…phase6…*.md` |
| Metering/venturi deep dive | `docs/design-metering-venturi.md` |
| MVP build spec | `docs/mvp-build-spec.md` |
| Parametric CAD (OpenSCAD) | `cad/*.scad`, renders in `cad/renders/` |
| Schematics & diagrams | `docs/diagrams/` (SVG sources + PNG) |
| MVP Build Pack web page | live: https://claude.ai/code/artifact/5ff84554-1ebf-416a-b2bb-9e4c18771d7c · archived: `docs/mvp-build-pack.html` |

## 10. Open items / watch list

- Founder to confirm the dose envelope holds for the launch formula set.
- Highest cost/delay risks (Phase 5): the ≥650-tonne press for the Ø47 cm
  carousel ring (few vendors — quote early), aseptic bag MOQ, UL timeline
  (3–4 months — start pre-review on polished prototypes).
- Wellness-claims legal review required before the app ships
  wearable-driven suggestions.

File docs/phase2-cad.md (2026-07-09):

# Neuro-Stream — Phase 2: Parametric CAD Model

**Status:** Draft for founder sign-off
**Date:** 2026-07-09
**Model:** [`cad/neuro-stream.scad`](../cad/neuro-stream.scad) (OpenSCAD 2021.01+)
**Renders:** [`cad/renders/`](../cad/renders/)

---

## 1. Layout decision: carousel, not drawer rack (for v1)

Phase 1 left the cartridge-presentation question open. Decided: **rotating
carousel** for the countertop v1.

- 10 × Ø80 mm cartridges in a straight rack (as in your renders) makes a
  ~950 mm-wide machine — a drawer works under a counter, not on one.
- A carousel packs the same 10 stations into a **Ø~440 mm, ~465 mm tall**
  cylinder — large-blender footprint.
- It needs only **one docking/drive station**: the carousel rotates the chosen
  cartridge over it. One drive motor + one cheap indexing motor serve all 10
  stations, which is the whole point of Architecture B.
- Your 4-ingredient recipe requirement is sequential: index → dock → dispense,
  four times. At ~5–16 s per ingredient plus ~1.5 s indexing, a 4-ingredient
  serving takes **~30–60 s**.
- The v2 under-counter drawer keeps the identical cartridge and docking-cone
  interface — only the presentation mechanism changes.

## 2. What's in the model

Open `cad/neuro-stream.scad`. Every dimension is a named variable at the top;
the geometry re-derives when you change them. Highlights:

| Variable | Value | What it controls |
|---|---|---|
| `n_stations` | 10 | Cartridge count — set 6 and the whole machine shrinks into a compact SKU |
| `cart_od` / `cart_h` | 80 / 220 | Cartridge envelope (≈1 L net) |
| `spline_d`, `spline_clr` | 10, 0.15 | The standard drive interface and its fit |
| `aug_*` | 16/8/8 | Powder dosing screw → ≈0.65 g/rev |
| `pist_id`, `pist_lead` | 20, 4 | Syrup piston pump → ≈1.26 mL/rev |
| `explode` | 0–1 | Exploded-view slider |
| `cross_section` | bool | Half-section through internals |

**View controls:** `explode=1` for the exploded assembly, `cross_section=true`
for a half-section, `show_*` flags to isolate subsystems. Render from CLI:

```
openscad -o out.png --imgsize=1200,900 --camera=0,0,230,65,0,35,1500 \
         -D explode=1 cad/neuro-stream.scad
```

## 3. Key tolerances and why (also commented in the model)

| Feature | Tolerance | Rationale |
|---|---|---|
| Spline socket↔shaft | 0.15 mm diametral | Absorbs POM molding variation (±0.05 mm typ.) + carousel positioning error while keeping rotational backlash <2°, so step-count dose error from lash stays <0.1% of one revolution |
| Docking cone seat | +0.2 mm on neck | Slip fit that still centres the outlet within ±0.3 mm over a 12 mm funnel throat |
| Carousel station bore | +0.4 mm on neck | Deliberately loose drop-in fit — a consumer must never have to aim; precision location comes from the cone, not the plate |
| Docking capture range | ±2.5 mm | Cone mouth vs. neck: the indexing motor + molded ring gear only need to be this accurate, so no precision gearing anywhere |
| Cartridge shell wall | 1.6 mm PP | PP flow-length sweet spot: <1.2 mm short-shots on a 220 mm part, >2.5 mm sinks and adds cycle time |
| Metering chamber (screw OD/bore) | ±0.05 mm (mold spec, SPI A-2 cavity) | Chamber volume variation is the largest open-loop dose error source; ±0.05 on Ø16 ≈ ±0.6% volume, leaving budget inside ±2% — and per-lot fill-line calibration absorbs the systematic part |

## 4. Dose math sanity check (±2% feasibility)

- **Powder (P2):** 0.65 g/rev; NEMA17 at 200 steps/rev through 1:5 gearing →
  0.65 mg per full step. A 5 g dose = ~7.7 rev = 5 s at 90 rpm. Quantization
  error is negligible; accuracy is governed by fill-fraction repeatability,
  which the agitator + per-lot calibration constant handle.
- **Syrup (L2):** 1.26 mL/rev → 30 mL ≈ 24 rev ≈ 16 s. Check-valve pair
  re-primes the piston from the aseptic bag; the one-way valve means no air
  ever back-fills the bag (founder's preservative-free requirement).
- **Micro-dose (P1, later):** same architecture with a smaller screw
  (`aug_barrel_id=8, aug_pitch=4` → ~0.08 g/rev, 1.25 rev minimum dose).

## 5. Part → manufacturing process map

### Machine (sellable unit)

| Part | Qty | Process | Notes |
|---|---|---|---|
| Chassis skirt + tower shells | 2 | **Injection mold** (ABS) | Largest tools in the program; texture spec MT-11010 |
| Internal deck plate | 1 | **Sheet metal** (1.5 mm galv.) | Flat + stiff + cheap at launch volume; convert to a 3rd molding above ~20k units/yr |
| Carousel plate w/ molded ring gear | 1 | **Injection mold** (30% GF-PP) | Molded gear is fine — cone does final location |
| Docking cone | 1 | **Injection mold** (GF-PP) | |
| Drive spline shaft (annular crown) | 1 | **CNC** (316L SS — Phase 4 correction) | The one precision machined part; product falls through its centre, torque enters around it |
| Drop funnel | 1 | **Injection mold** (Tritan) | Only user-washed food-contact part; twist-lock, dishwasher-safe |
| Weigh platform / drip tray | 2 | **Injection mold** (ABS / PP) | |
| Lid | 1 | **Injection mold** (clear PC) | |
| Drive stepper + 1:5 planetary | 1 | **OTS** | NEMA17 class |
| Carousel index stepper + pinion | 1 | **OTS** | |
| Carousel bearing (slew ring) | 1 | **OTS** | Lazy-susan class, not precision |
| Load cell 1 kg + mounts | 1 | **OTS** | TAL221 class |
| Lift cam, spring, small hardware | — | **OTS** | |
| NFC reader module | 1 | **OTS** | Reads cartridge tag at dock |

### Powder cartridge (P2) — 7 parts, all high-volume

| Part | Process |
|---|---|
| Shell + integral neck | Injection mold, PP (food-contact grade) |
| Dosing screw + agitator (one part) | Injection mold, POM |
| Outlet wiper/duckbill seal | LSR micro-mold |
| Foil induction seal | OTS converting |
| Desiccant puck | OTS |
| NFC tag inlay | OTS |
| Snap base cap | Injection mold, PP |

### Syrup cartridge (L2) — 8 parts

| Part | Process |
|---|---|
| Shell | Injection mold, PP |
| Piston pump block + leadscrew (2 pts) | Injection mold, POM |
| Inlet + outlet check valves (2 pts) | LSR micro-mold |
| Aseptic collapsible bag + one-way valve | OTS (bag-in-box industry standard, sterile-filled) |
| NFC tag inlay | OTS |

## 6. Open items flagged for founder

1. **Stirring/dissolution:** the machine dispenses up to 4 ingredients into the
   glass but does not stir. Powders like greens blends need agitation to
   dissolve. Options: (a) user stirs — recommended for v1, zero cost;
   (b) magnetic stirrer coil under the weigh platform + a puck in a branded
   shaker cup (~$6 BOM); (c) defer to v2. **Recommendation: (a), with (b) as a
   fast-follow accessory.**
2. **Compact SKU:** `n_stations=6` yields a Ø~350 mm machine from the same
   parts. Worth deciding before tooling, since the carousel tool would differ.
3. This is a **concept-geometry model** — correct architecture, envelopes,
   interfaces, and tolerances for review. Production surfacing (ribs, bosses,
   draft angles, snap details) belongs in a mechanical-CAD package (Fusion/
   SolidWorks) during Phase 5 DFM; the .scad stays the dimensional source of
   truth until then.

---

## 7. AMENDMENT — Water / heating / mixing subsystem (founder-approved 2026-07-09)

Founder decision: v1 must dissolve powders and incorporate liquids properly,
and must deliver water at a user-set temperature within **±2 °F**. Scope
change adopted: v1 gains a **tank-fed hot-water system with in-stream venturi
mixing** (this supersedes the "user stirs" recommendation in §6.1).

**Architecture** (now in the parametric model, `show_water=true`):

- **Removable ~3.5 L Tritan tank in the dead centre of the carousel ring** —
  the carousel is rim-driven, so its middle is empty; the tank lives there and
  lifts out through the lid. Machine footprint is unchanged.
- Water path: tank → poppet coupling → diaphragm pump → hall flow meter →
  **1200 W inline thick-film heater** (PID against outlet NTC + measured
  flow) → tangential inlet of the **venturi/swirl mixing manifold** mounted
  under the docking cone. Dosed ingredients drop from the cartridge outlet
  directly into the swirling heated stream and dissolve in-line before the
  spout. The manifold replaces the drop funnel as the single user-removable,
  dishwasher-safe food-contact part.
- **±2 °F at spout** is a firmware deliverable (Phase 3 PID + feed-forward on
  flow); heater-only system heats from tank temperature up to ~205 °F —
  chilling remains a v2 feature.
- Consequences accepted: mains-only power (1200 W kills battery), UL
  heating-appliance certification path (+$15–30k, +2–3 months), NSF/ANSI 42
  attention on the water path, descaling routine, added BOM ~$30–45.

**Sign-off status:** carousel layout, 10-station envelope, and Ø80×220
cartridge confirmed by founder ("go forward", 2026-07-09) together with this
subsystem. Mixing decision resolved: **venturi in-stream mixing** (no stirrer).

---

**→ Phase 3: electronics & firmware** (see `docs/phase3-electronics-firmware.md`)

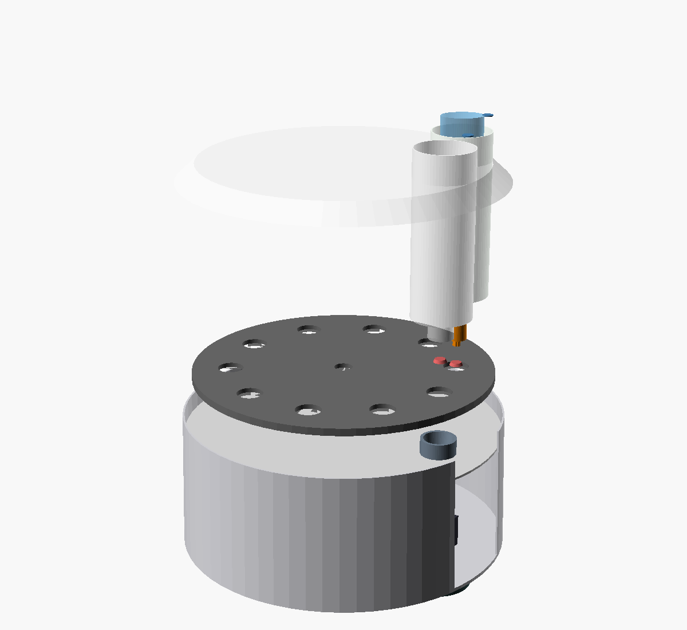
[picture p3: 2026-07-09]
cad/renders/exploded.png

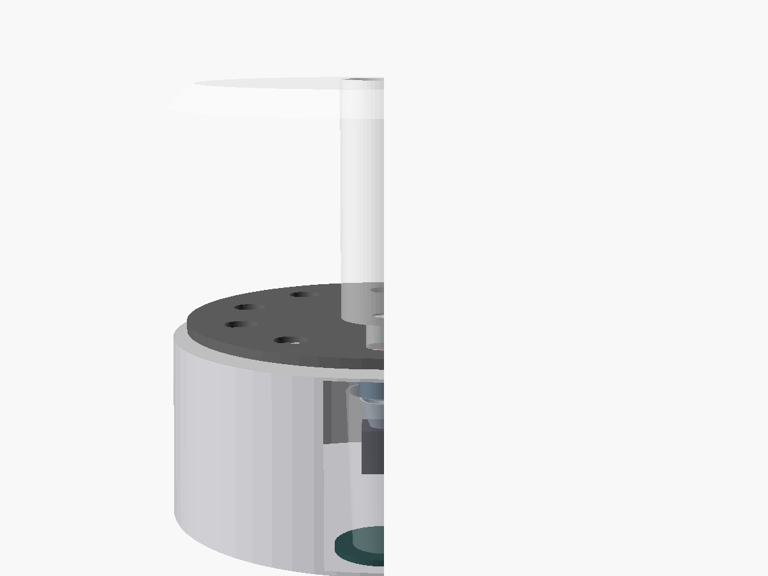
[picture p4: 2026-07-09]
cad/renders/section.png

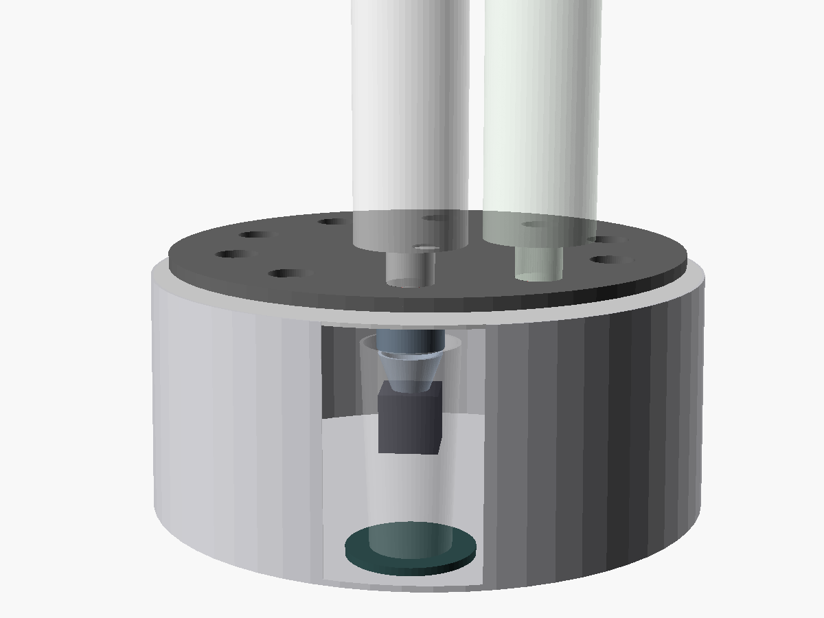
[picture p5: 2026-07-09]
cad/renders/front-bay.png

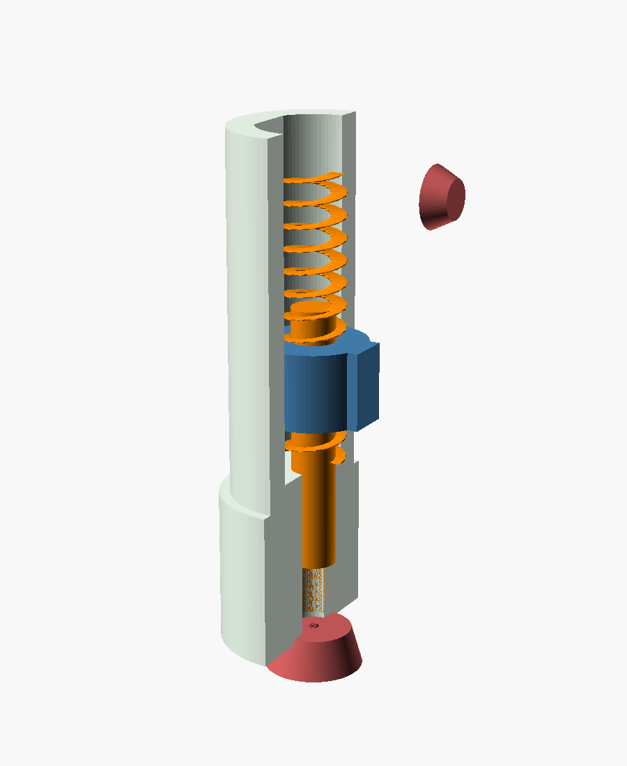
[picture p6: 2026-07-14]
cad/renders/cart-syrup.png

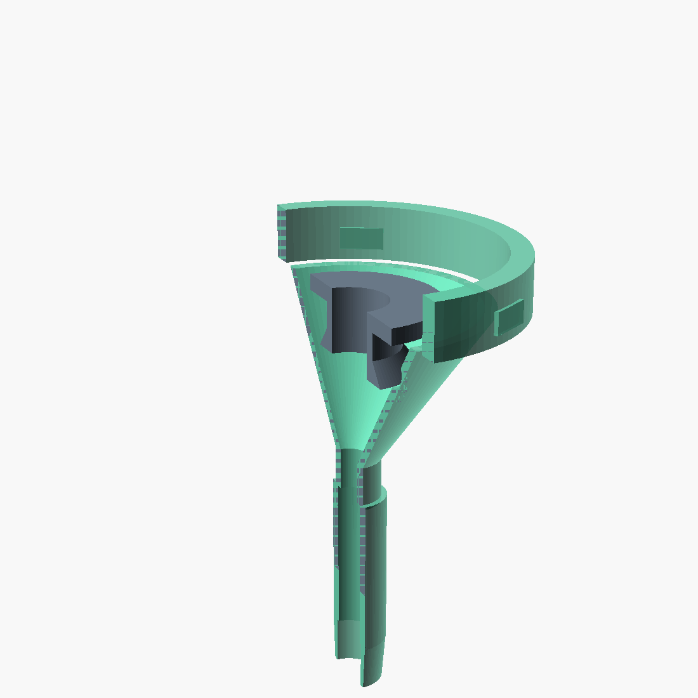
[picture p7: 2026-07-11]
cad/renders/venturi-detail.png

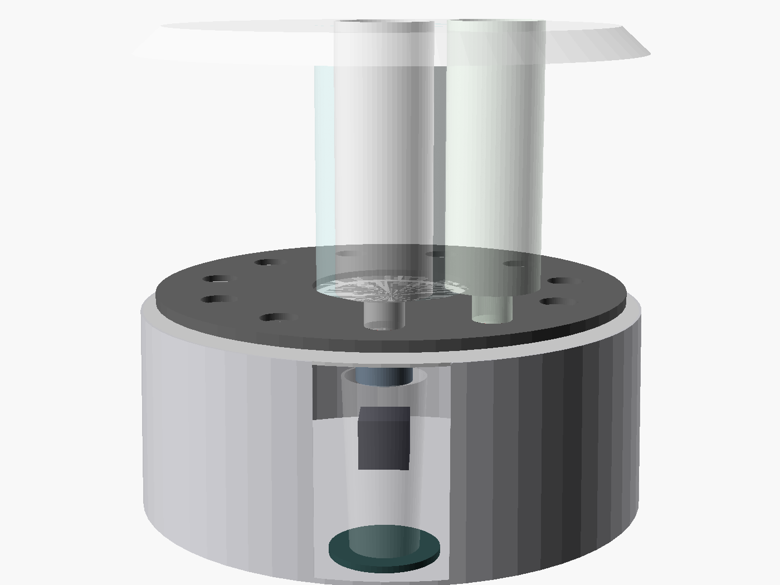
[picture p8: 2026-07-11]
cad/renders/v-front.png

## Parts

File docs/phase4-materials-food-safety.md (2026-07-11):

# Neuro-Stream — Phase 4: Materials & Food-Safety Compliance

**Status:** Draft for founder sign-off
**Date:** 2026-07-09
**Scope:** food-contact material selection per part (FDA 21 CFR 177),
certification flags, cleaning/sanitation requirements.

> Not legal advice: final compliance sign-off belongs with a food-contact
> regulatory consultant before tooling kickoff. This phase specifies materials
> with clear regulatory pathways so that review is a formality, not a redesign.

---

## 1. Formula-contact and water-contact parts, material by material

### 1.1 Cartridge (formula contact — the critical set)

| Part | Material | FDA pathway | Notes |
|---|---|---|---|
| Shell + neck | Polypropylene (homopolymer, food grade) | **21 CFR 177.1520** (olefin polymers) | Choose a resin with supplier FCS letter of guarantee; natural (unpigmented) inner surface |
| Dosing screw / piston block, leadscrew | Acetal (POM) copolymer | **21 CFR 177.2470** | Standard for food-machinery gears/screws; low friction, no lubricant needed (any grease in the product path must be NSF H1, but the design needs none) |
| Outlet wiper / duckbill / check valves | Platinum-cured LSR silicone | **21 CFR 177.2600** (rubber articles, repeated use) | Platinum-cure only — peroxide-cured silicone leaves volatiles; verify extractables per 177.2600 (e) |
| Aseptic collapsible bag | PE sealant / EVOH barrier laminate | PE: **177.1520**; EVOH: **177.1360** | Standard aseptic bag-in-box stack; buy as a converted component from an aseptic-bag supplier with existing FDA compliance docs |
| One-way bag valve | PE/silicone | as above | OTS from same bag supplier |
| Foil induction seal | Alu/PE lamination | **177.1520** + GRAS aluminum | Industry standard |
| Desiccant puck (powder SKU) | Silica gel in Tyvek/PE housing | Indirect contact; use FDA-grade dessicant pack | OTS (Multisorb-class) |
| NFC tag inlay | — | **No product contact** — bonded to shell exterior | Keep it outside; zero compliance burden |

### 1.2 Machine water path (water contact)

| Part | Material | Pathway | Notes |
|---|---|---|---|
| Water tank | Eastman Tritan copolyester | FDA-cleared via Eastman FCNs | BPA-free story is also a marketing asset; dishwasher-safe |
| Tank poppet coupling | PP + EPDM O-ring | 177.1520 / 177.2600 | EPDM must be potable-water grade |
| Pump (wetted path) | Buy **food/potable-grade pump** (PP/EPDM wetted) | Supplier declaration | Spec at sourcing time — many diaphragm pumps are not potable-rated |
| Water tubing | Platinum-cured silicone | 177.2600 | High-temp rated (post-heater segment sees ~96 °C) |
| Inline heater wetted surface | 316L stainless steel | GRAS / accepted food-contact metal | Thick-film heaters with 316L flow tubes are standard coffee-machine parts |
| Flow meter body | PP/POM potable-rated | 177.1520 / 177.2470 | OTS potable-rated part |
| Venturi mixing manifold + spout | Tritan | Eastman FCNs | The one user-washed part; must survive 1000+ dishwasher cycles |

### 1.3 Machine parts near, but not touching, product

Docking cone (GF-PP), carousel (GF-PP), chassis (ABS), lid (PC): **no direct
product contact by design** — the cartridge's own outlet passes through the
cone and delivers into the venturi. Keeping these out of the food-contact set
is deliberate: glass-filled and flame-retardant grades are hard to clear for
contact, and this design never needs to.

### 1.4 One correction from Phase 2

The spline drive shaft was drafted as **303 stainless** (free-machining).
303's sulfur content makes it a poor food-adjacent choice; although the shaft
is nominally non-contact (annular, around the outlet), powder dust will settle
on it. **Changed to 316L, machined.** Cost delta ≈ +$0.40/unit. The .scad
comment will be updated when the model is next touched.

## 2. Certification & testing flags

| Requirement | Applies to | When |
|---|---|---|
| **UL/ETL 60335-2-15** (household water-heating appliances) | Whole machine (heater!) | Mandatory for US retail; the heater moved us from the simple motor-appliance category into this one. Budget $25–40k, 3–4 months, engage the lab at EVT stage |
| **FCC Part 15 + intentional radiator** | ESP32-S3 Wi-Fi/BLE | Use the module's existing modular certification to cut cost/time; still need end-product verification |
| **NSF/ANSI 42** (or NSF/ANSI 51 materials listing) | Water path | Not legally mandatory for a consumer countertop unit, but retailers (Costco/Williams-Sonoma/Amazon brand registry) increasingly ask; the materials above are chosen to pass without change |
| **FDA food-contact compliance file** | All §1 parts | Assemble Letters of Guarantee from every resin/component supplier pre-tooling; consultant review ≈ $8–15k |
| **CA Prop 65** | Whole product | Verify no listed substances (mind brass fittings — use none) |
| **Cartridge filling operation** | Your fill line / co-packer | This is the big one outside the device: filling ingestible cartridges is **dietary-supplement manufacturing under 21 CFR 111 cGMP** — FDA-registered facility, lot traceability, stability data. Choose a co-packer who already holds this; do not build it yourself for launch |
| Wellness-claims guardrail | App + marketing | Health-data-driven dosing stays "suggestions" (see Phase 3 §6.2) or FDA SaMD risk attaches |

## 3. Cleaning & sanitation design requirements

> **SUPERSEDED in part by §5 (founder-approved self-cleaning model,
> 2026-07-09).** The design rules at the end of this section still apply;
> the user-facing regimen table is replaced by §5.

The design's core sanitation argument: **every formula's wetted path is
disposable** (lives in the cartridge, replaced ~monthly), and the shared path
is exactly two things — the venturi manifold and the spout.

Resulting user-facing regimen (this becomes manual + app copy):

| Task | Frequency | How |
|---|---|---|
| Venturi manifold + spout | Weekly (or on ingredient-class change) | Twist off, top-rack dishwasher. Machine reminds via screen; interlock detects it missing and refuses to dispense |
| Self-rinse | Every serving | Automatic 20 mL hot flush (firmware, Phase 3) — this is why weekly (not daily) manual washing is defensible |
| Water tank | Weekly | Rinse; dishwasher-safe monthly |
| Drip tray / weigh platform | Weekly | Sink or dishwasher |
| Descale cycle | Every 3 months (hardness-adjusted) | Citric-acid cycle, screen-guided, ~15 min; firmware tracks liters-since-descale |
| Deep water-path sanitize | Every 6 months | Dilute NaOCl or percarbonate cycle + double rinse, screen-guided |
| Docking cone wipe | Monthly | Damp cloth; no disassembly |

Design rules locked by this phase:
- No shared surface that a *formula* touches except venturi + spout (both
  user-removable, dishwasher-safe, transparent so soiling is visible).
- No crevices <1 mm radius in any wetted molded part (mold spec).
- All wetted materials rated ≥ 100 °C (hot flush + dishwasher + descale chemistry).
- Silicone water lines replaceable as a service part without tools beyond a
  Phillips screwdriver (10-year serviceability posture).

---

## 5. AMENDMENT — Self-cleaning model (founder-approved 2026-07-09)

Founder requirement: **the user should never have to clean the machine.**
Adopted design:

- **11 carousel slots** (was 10): 10 ingredient cartridges + **1 dedicated
  slot for a cleaning cartridge**. Machine grows to Ø~47 cm.
- **Cleaning cartridge SKU** (3rd cartridge type): same body/neck/tag as
  ingredient cartridges; two chambers — food-safe detergent/sanitizer
  concentrate + citric-acid descaler. Ships in every subscription box.
  Machine reads the tag, knows when cleaning last ran, and prompts.
- **Overnight self-clean cycle** (~30 min, scheduled by user, runs unattended):
  hot detergent flush of venturi/spout/water path → soak → descale stage when
  needed → triple rinse. Effluent (~1–1.5 L) exits the normal spout into a
  **user-placed container that the load cell verifies is present and large
  enough before the cycle will start**. (Direct sink drain is a v2
  under-counter feature.)
- **Water-tank filter cartridge** (Brita-class, ~$2 BOM + consumable):
  cuts scale, stretches descale interval, improves taste.
- **Conductivity sensor** (~$1 BOM): measures actual water hardness so
  descaling is scheduled by need, not calendar.
- Residual user tasks: place a container the night a clean runs; rinse the
  drip tray occasionally. Everything else is automatic (including the 20 mL
  hot rinse after every serving).
- Firmware additions (annexed to Phase 3 spec): cleaning-cycle state machine,
  container-mass check, hardness-based descale scheduler, cleaning-cartridge
  tag handling, "won't dispense while cleaning-overdue > 2 weeks" nag policy.

---

**✅ SIGN-OFF STATUS (in the simplest terms):**

1. **The plastics and metals list (§1)** — **approved by founder 2026-07-10**
2. **The safety-testing plan and budget (§2, ~$35–55k)** — **approved by
   founder 2026-07-10**
3. **Self-cleaning model (§5)** — **approved by founder 2026-07-09** (11
   slots, cleaning cartridge, overnight cycle, tank filter, hardness sensor)
4. → Phase 5: manufacturing plan and tiered pricing. **Volume path approved
   2026-07-10: MVP → 150-unit beta → scale.**

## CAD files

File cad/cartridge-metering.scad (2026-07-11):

// ============================================================================
// NEURO-STREAM — Cartridge metering internals (deep design, prototype-ready)
// Companion to neuro-stream.scad (machine-level model).
//
// TWO MECHANISMS IN THIS FILE:
//   part = "powder"  → dosing-screw assembly (class P2)
//   part = "syrup"   → piston pump assembly  (class L2)
//   part = "both"    → side by side
//
// PROTOTYPE INTENT: geometry is printable for bench testing —
//   screw/agitator + pump parts: SLS/MJF nylon or machined POM
//   barrels/housings: SLA clear resin (watch the powder/syrup move)
//   seals: cast or bought silicone (see notes)
// Bench tolerances (printed): ±0.2 mm — fine for dose-physics testing.
// Production tolerances (molded): metering bore ±0.05 mm (SPI A-2 cavity).
// ============================================================================

part          = "both";   // "powder" | "syrup" | "both"
explode       = 0;        // 0 assembled … 1 exploded
half_section  = false;    // cut housings to show internals
$fn = 96;

ex = explode;
function exz(mm) = ex*mm;

// ---------------------------------------------------------------------------
// SHARED: neck + 6-lobe spline socket (matches machine drive, spline_d=10)
// ---------------------------------------------------------------------------
neck_od     = 34;
neck_h      = 28;
outlet_d    = 12;
spline_d    = 10;
spline_lobes= 6;
spline_len  = 12;
spline_clr  = 0.15;   // POM socket vs 316L shaft — see machine model rationale

module spline_socket_negative() {   // subtract from driven part
    r = spline_d/2 + spline_clr/2;
    linear_extrude(spline_len+0.5)
        for (i=[0:spline_lobes-1])
            rotate(i*360/spline_lobes) translate([r*0.55,0]) circle(r=r*0.5);
}

// ============================================================================
// POWDER DOSING SCREW  (class P2: 2–15 g servings, target 0.65 g/rev)
// ============================================================================
// DESIGN NOTES (the details that make ±2% real):
//  * Dose/rev = π/4·(D²−d²)·pitch·fill ≈ 1.09 cm³ → ~0.65 g/rev @ 0.6 g/cm³.
//    Fill fraction is the variable — per-lot calibration absorbs its mean;
//    the geometry below controls its VARIANCE:
//  * 3 full flights inside the barrel → powder in the metering zone is fully
//    confined; only the last flight's state varies serving-to-serving.
//  * Agitator arms sweep 2 mm above the barrel entry slot at 1:1 screw speed —
//    keeps the slot flooded (constant head) from full to empty. This is the
//    single most important feature for no-drift-across-cartridge-life.
//  * Hopper cone at 60° from horizontal (steeper than any target powder's
//    angle of repose + 15° margin) → mass flow, no rat-holing.
//  * End-of-dose: firmware reverses 0.5 rev ("suck-back") to decompress the
//    last flight, then the duckbill wiper closes. Kills after-dribble.
//  * Torque budget: cohesive powder shear in this barrel ≈ 0.05–0.12 N·m;
//    spline + POM screw rated 0.5 N·m (4× margin). NEMA17+1:5 delivers 2 N·m.

aug_barrel_id = 16;      // metering bore (THE precision dimension, molded ±0.05)
aug_root_d    = 8;
aug_pitch     = 8;
aug_flight_t  = 2.2;     // flight thickness
aug_turns_in  = 3;       // flights confined in barrel
barrel_wall   = 2.5;
barrel_len    = aug_turns_in*aug_pitch + 6;
entry_slot_w  = 14;      // barrel entry slot (top side, under agitator)
entry_slot_l  = 16;
hopper_angle  = 60;      // deg from horizontal — anti-bridging
hopper_top_d  = 74;      // matches cartridge shell ID
agit_arm_r    = 33;      // agitator sweep radius
agit_clear    = 2;       // arm height above hopper floor

module powder_screw() {
    // one molded/printed part: spline socket + screw + agitator arms
    color("DarkOrange") difference() {
        union() {
            // screw root through barrel + up into hopper
            translate([0,0,-barrel_len]) cylinder(d=aug_root_d, h=barrel_len+8);
            // helical flight (true helix)
            translate([0,0,-barrel_len])
                linear_extrude(barrel_len, twist=-360*barrel_len/aug_pitch,
                               slices=barrel_len*6, convexity=10)
                    translate([(aug_root_d+ (aug_barrel_id-aug_root_d)/2)/2 - aug_root_d/4 + aug_root_d/2 - ((aug_barrel_id-aug_root_d)/4),0])
                        square([(aug_barrel_id-aug_root_d)/2, aug_flight_t], center=true);
            // hub above hopper floor
            translate([0,0,6]) cylinder(d=14, h=8);
            // two agitator arms, swept tips, 2 mm over hopper floor
            for (a=[0,180]) rotate(a)
                translate([0,0,agit_clear+8]) hull() {
                    translate([6,0,0])        sphere(d=6);
                    translate([agit_arm_r,0,10]) sphere(d=6);  // rises along cone
                }
        }
        translate([0,0,-barrel_len-0.4]) spline_socket_negative();
    }
}

module powder_housing() {
    // barrel + hopper cone + neck (cartridge-bottom insert, one molded part)
    color("WhiteSmoke", half_section?1:0.45) difference() {
        union() {
            // neck
            translate([0,0,-neck_h]) cylinder(d=neck_od, h=neck_h);
            // barrel body
            translate([0,0,-barrel_len]) cylinder(d=aug_barrel_id+2*barrel_wall, h=barrel_len);
            // hopper cone
            cylinder(d1=aug_barrel_id+2*barrel_wall, d2=hopper_top_d,
                     h=(hopper_top_d-aug_barrel_id)/2*tan(hopper_angle));
        }
        // metering bore
        translate([0,0,-barrel_len-1]) cylinder(d=aug_barrel_id, h=barrel_len+2);
        // hopper interior
        translate([0,0,0.01])
            cylinder(d1=aug_barrel_id, d2=hopper_top_d-4,
                     h=(hopper_top_d-aug_barrel_id)/2*tan(hopper_angle));
        // entry slot from hopper into barrel top flight
        translate([-entry_slot_l/2,-entry_slot_w/2,-aug_pitch-2])
            cube([entry_slot_l, entry_slot_w, aug_pitch+3]);
        // outlet bore through neck
        translate([0,0,-neck_h-1]) cylinder(d=outlet_d, h=neck_h+2);
        if (half_section) translate([0,-100,-200]) cube([200,200,400]);
    }
}

module duckbill_seal() {
    // LSR duckbill at outlet: powder passes down, humidity blocked upward.
    // Prototype: buy Ø12 silicone duckbill (Minivalve-class); this is a stand-in.
    color("IndianRed") translate([0,0,-neck_h-6-exz(25)]) {
        difference() {
            cylinder(d1=outlet_d+6, d2=outlet_d+2, h=7);
            translate([0,0,-0.5]) cylinder(d1=outlet_d+2, d2=2, h=7.5);
        }
    }
}

module powder_assembly() {
    powder_housing();
    translate([0,0,exz(70)]) powder_screw();
    duckbill_seal();
}

// ============================================================================
// SYRUP PISTON PUMP  (class L2: 5–50 mL servings, 1.26 mL/rev)
// ============================================================================
// DESIGN NOTES:
//  * Rotation→stroke inside the cartridge: spline turns a leadscrew (lead
//    4 mm) engaged in the piston's molded nut; piston is keyed against
//    rotation by two flats in the bore.  1 rev = 4 mm × π·10² = 1.26 mL.
//  * Full stroke 40 mm = 12.6 mL per stroke. Doses >12.6 mL auto-cycle:
//    dispense-stroke → fast retract (re-prime from bag) → repeat.
//  * Re-prime physics (the risky bit for 20,000 cP syrup): retract at
//    ≤6 mm/s with Ø8 inlet → bag pressure (collapsible, ~0.05 bar elastic
//    + atmospheric) refills in 4–7 s worst case. Firmware paces retract
//    speed by syrup viscosity class from the NFC tag. PROTOTYPE MUST VERIFY.
//  * Check valves: inlet umbrella (cracks 0.03 bar, low restriction),
//    outlet duckbill (cracks 0.15 bar — holds column, no drip). End-of-dose
//    reverse ¼ rev decompresses the bore.
//  * Piston seal: single X-ring (quad ring), silicone, Ø20 bore — lower
//    friction than O-ring, no lubricant (dry POM bore, Ra 0.4).
//  * Accuracy: displacement is geometric — bore ±0.05 mm ⇒ ±0.5% volume;
//    leadscrew molded pitch error <0.3%; both absorbed by per-lot k_cal.

pist_bore   = 20;
pist_stroke = 40;
lead        = 4;
pump_od     = 30;
pump_len    = pist_stroke + 26;
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

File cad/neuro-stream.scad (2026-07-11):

// ============================================================================
// NEURO-STREAM v1 — Parametric concept model (Phase 2)
// Countertop 10-station smart-cartridge dispenser, Architecture B
//
// OpenSCAD 2021.01+.  All dimensions in millimetres.
//
// HOW TO USE
//   explode = 0;          assembled view
//   explode = 1;          fully exploded view (parts translate apart)
//   cross_section = true; cut the model in half to see internals
//   show_* flags          isolate subsystems
//
// MANUFACTURING FLAGS (also repeated per-module):
//   [IM]  injection molded        [CNC] machined
//   [SM]  sheet metal             [OTS] off-the-shelf purchased part
//   [EXT] extrusion, cut to length
// ============================================================================

// ---------------------------------------------------------------------------
// VIEW CONTROLS
// ---------------------------------------------------------------------------
explode        = 0;      // 0 = assembled … 1 = fully exploded
cross_section  = false;  // true = half-section through machine centreline
show_chassis   = true;
show_carousel  = true;
show_cartridges= true;   // one powder + one syrup cartridge shown docked
show_drive     = true;
show_dispense  = true;   // funnel, load-cell platform, drip tray
show_lid       = true;
show_water     = true;   // tank, pump, heater, venturi mixing manifold
lid_open       = 0;      // 0 = closed … 75 = flipped open on rear hinge (deg)
show_screen    = true;   // 2.8" touchscreen on the front face

$fn = 64;                // curve resolution (raise for exports)

// ---------------------------------------------------------------------------
// MASTER PARAMETERS — the numbers you will actually tune
// ---------------------------------------------------------------------------

// ---- Cartridge envelope (shared by all cartridge SKUs) --------------------
cart_od          = 80;    // cartridge body outer dia. 80 dia × 220 tall ≈ 1.0 L net
cart_h           = 220;   // cartridge body height (above neck)
cart_wall        = 1.6;   // [IM] PP shell wall. 1.6 mm is the sweet spot for
                          // PP flow length vs. rigidity; <1.2 warps, >2.5 sinks.
cart_neck_od     = 34;    // neck that seats into the docking station
cart_neck_h      = 28;    // neck engagement length
cart_outlet_d    = 12;    // product outlet bore

// ---- Standard drive interface (THE precision interface of the machine) ----
// 6-lobe spline socket molded into every cartridge metering element; mating
// steel spline shaft rises from the drive station.
spline_d         = 10;    // spline major dia
spline_lobes     = 6;
spline_len       = 12;    // axial engagement
spline_clr       = 0.15;  // TOLERANCE: fit clearance between molded POM socket
                          // and machined steel shaft. 0.15 mm absorbs molding
                          // variation (±0.05 typ. for a 10 mm POM feature) plus
                          // carousel positioning error, while keeping rotational
                          // backlash < 2° so step-counted dose error from lash
                          // stays below 0.1% of a 1-revolution dose.
spline_lead_in   = 2;     // chamfer so blind docking self-aligns

// ---- Carousel & station geometry -------------------------------------------
n_stations       = 11;    // FOUNDER-APPROVED 2026-07-09: 11 slots =
                          // 10 ingredient cartridges + 1 dedicated slot for
                          // the self-cleaning cartridge. Set 6 for a compact
                          // SKU — everything below re-derives automatically.
station_gap      = 15;    // clearance between adjacent cartridge bodies
pitch_c          = n_stations * (cart_od + station_gap);   // pitch circumference
pitch_r          = pitch_c / (2 * PI);                     // station pitch radius
carousel_r       = pitch_r + cart_od/2 + 12;               // carousel disc radius
carousel_t       = 6;     // [IM] carousel plate thickness (glass-filled PP)
station_bore     = cart_neck_od + 0.4;  // TOLERANCE: neck-to-plate fit. +0.4 mm
                          // diametral = drop-in fit for a consumer with no
                          // aiming; radial location comes from the tapered
                          // docking cone below, not this bore.

// ---- Chassis ----------------------------------------------------------------
deck_h           = 185;   // carousel deck height above countertop. Must exceed
                          // glass_h + funnel_h + 25 mm clearance.
base_r           = carousel_r + 18;   // chassis skirt radius
base_wall        = 2.5;   // [IM] ABS enclosure wall
glass_h          = 150;   // tallest vessel the dispense bay accepts
bay_w            = 110;   // dispense bay opening width

// ---- Powder metering element (class P2) -------------------------------------
// Vertical dosing screw in the cartridge neck, agitator on the same shaft.
aug_barrel_id    = 16;    // [IM] barrel bore molded into neck insert
aug_root_d       = 8;     // screw root dia
aug_pitch        = 8;     // flight pitch
aug_turns        = 3;     // flights inside the barrel
// dose/rev ≈ π/4·(id²−root²)·pitch·fill ≈ 1.09 cm³/rev ≈ 0.65 g/rev @0.6 g/cm³.
// A 5 g serving ≈ 7.7 rev; at 90 rpm that is a 5 s dispense. Resolution per
// motor full-step (200 steps/rev, 1:5 gear) ≈ 0.65 mg — far inside ±2%.
agitator_r       = cart_od/2 - cart_wall - 4;  // sweep radius of agitator flight

// ---- Syrup metering element (class L2) --------------------------------------
// Piston displacement pump driven through an internal leadscrew from the same
// rotary spline — cartridge converts rotation to linear stroke internally.
pist_id          = 20;    // piston bore
pist_stroke      = 40;    // max stroke per re-prime cycle
pist_lead        = 4;     // leadscrew lead: 4 mm/rev → 1.26 mL/rev.
// 30 mL serving ≈ 24 rev ≈ 16 s at 90 rpm. Check-valve pair re-primes from bag.

// ---- Drive station -----------------------------------------------------------
drive_travel     = 14;    // vertical engage/retract stroke of spline shaft
motor_l          = 42;    // [OTS] NEMA17 stepper + 1:5 planetary
cone_big_d       = cart_neck_od + 6;   // docking cone mouth
cone_small_d     = cart_neck_od + 0.2; // TOLERANCE: cone seat. +0.2 mm on the
                          // neck gives a slip fit that still centres the outlet
                          // over the funnel within ±0.3 mm — powder stream and
                          // syrup drip both land inside a 12 mm funnel throat.

// ---- Dispense bay -------------------------------------------------------------
funnel_top_d     = 46;    // [IM] shared drop funnel, dishwasher-safe, tool-less
funnel_bot_d    = 14;
funnel_h         = 38;
loadcell_l       = 55;    // [OTS] 1 kg single-point load cell (TAL221-class)
platform_d       = 95;    // [IM] weighing platform / drip tray top

// ---- Water / heating / mixing subsystem (founder-approved 2026-07-09) ---------
// Tank lives in the dead space inside the carousel ring: zero footprint cost.
tank_d           = 140;   // [IM] removable tank, Ø140 × 250 ≈ 3.5 L usable
tank_h           = 250;
tank_wall        = 2.0;   // Tritan (clear, tough, dishwasher-safe)
pump_l           = 55;    // [OTS] diaphragm pump body length (base compartment)
heater_l         = 90;    // [OTS] inline thick-film heater, 1200 W
heater_d         = 32;
tube_d           = 8;     // silicone water line, 8 mm OD
// TOLERANCE: tank-to-base water coupling uses a spring poppet + EPDM O-ring;
// coupling bore +0.1/-0 on a Ø14 spigot — sealing comes from the O-ring
// squeeze (25% nominal), not the bore fit, so molding variation is absorbed.
venturi_l        = 34;    // [IM Tritan] mixing manifold: heated water enters
venturi_d        = 22;    //   tangentially, product drops in from the cone
                          //   above, swirl + venturi throat dissolves powder
                          //   in-stream before the spout. Removable for wash.
spout_d          = 10;

// ---- Lid ----------------------------------------------------------------------
lid_h            = 24;    // [IM] hinged translucent lid over cartridge deck

// Exploded-view translation distances (scaled by `explode`)
ex   = explode;
function exz(mm) = ex * mm;   // axial explode helper

// ============================================================================
// PART MODULES
// ============================================================================
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

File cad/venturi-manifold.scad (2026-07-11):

// ============================================================================
// NEURO-STREAM — Mixing manifold deep design (prototype-ready)
//
// HONEST ENGINEERING NOTE (why this is a "swirl wetting cone", and the pure
// venturi idea evolved): at our pump flow (~0.5 L/min = 8.3 mL/s) water
// velocities are ~0.3–0.9 m/s — venturi suction at that speed is only
// ~100–400 Pa: too weak to *entrain* powder reliably. What actually works at
// this scale (and is how commercial powder-drink and fountain machines do
// it) is a WET-WALL SWIRL CONE:
//   * water enters TANGENTIALLY at the top rim → spins into a thin film
//     coating the entire cone wall (a "wet wall")
//   * powder falls from the cartridge outlet onto the moving film — every
//     particle lands on water already in motion, so it wets instantly and
//     cannot form dry clumps or stick to a dry wall
//   * film converges into the throat where the flow necks down (this is the
//     venturi-like part) → intense shear finishes dissolution
//   * a short mixing tube (3× throat dia) evens it out before the spout
// Steam/splash management matters more than suction: hot water at the rim
// creates vapor that would wet the powder chute and cake it. Hence the
// VAPOR SHIELD: a molded baffle ring separating the (dry) powder drop path
// from the (wet) rim region, with a condensation drip edge.
//
// Numbers at design flow 8.3 mL/s (0.5 L/min):
//   tangential inlet Ø6  → v_in   = 0.29 m/s (film launch speed)
//   throat Ø7            → v_thr  = 0.22 m/s bulk; film Reynolds ≈ 2,600
//   full serving 250 mL  → 30 s water; ingredients co-dispense in-stream
//   pressure drop total  < 4 kPa → any diaphragm pump shrugs
// Prototype MUST verify: greens-blend (worst wetter) 5 g into 250 mL with
// zero residue on walls and <10 s dissolution tail. Knobs if it fails:
// inlet Ø down to 4.5 (faster film), cone angle, second tangential inlet.
// ============================================================================

half_section = true;    // the useful view for this part
explode      = 0;
$fn = 120;

ex = explode;

// ---- Parameters (the tuning knobs) -----------------------------------------
cone_top_d    = 46;    // rim where water film launches
cone_angle    = 55;    // wall angle from horizontal; steeper = faster film
throat_d      = 7;     // neck-down: shear zone. THE dissolution knob.
throat_len    = 8;
mixtube_d     = 9;
mixtube_len   = 27;    // ≈3× throat dia — evens concentration before spout
spout_d       = 10;
wall          = 2.2;   // Tritan molded (prototype: clear SLA to watch flow)
inlet_d       = 6.0;   // tangential water inlet (production: molded-in barb)
inlet_h_below_rim = 6;
powder_tube_d = 14;    // dry drop path from cartridge outlet (Ø12 + clearance)
shield_gap    = 3;     // vapor-shield annular gap (condensate drip edge)
twist_lock_d  = 54;    // bayonet ring engaging the machine (user-removable)

cone_h = (cone_top_d-throat_d)/2*tan(cone_angle);

module manifold_body() {
    difference() {
        union() {
            // outer shell: cone + throat + mixing tube
            cylinder(d1=throat_d+2*wall, d2=cone_top_d+2*wall, h=cone_h);
            translate([0,0,-throat_len]) cylinder(d=throat_d+2*wall, h=throat_len+1);
            translate([0,0,-throat_len-mixtube_len]) cylinder(d=mixtube_d+2*wall, h=mixtube_len+1);
            translate([0,0,-throat_len-mixtube_len-8]) cylinder(d1=spout_d+2, d2=mixtube_d+2*wall, h=8.5);
            // rim + twist-lock ring
            translate([0,0,cone_h]) difference() {
                cylinder(d=twist_lock_d+8, h=10);
                translate([0,0,-0.5]) cylinder(d=twist_lock_d, h=11);
            }
            translate([0,0,cone_h+4]) for(a=[0,120,240]) rotate(a)  // 3 bayonet lugs
                translate([twist_lock_d/2+2,0,0]) cube([5,8,4], center=true);
            // tangential inlet boss
            translate([0,0,cone_h-inlet_h_below_rim]) rotate([0,90,0])
                translate([0, cone_top_d/2-6, 0]) cylinder(d=inlet_d+2*wall, h=cone_top_d/2+14);
        }
        // interior: cone
        translate([0,0,-0.01]) cylinder(d1=throat_d, d2=cone_top_d, h=cone_h+0.02);
        // throat + mixing tube + spout bores
        translate([0,0,-throat_len-0.5]) cylinder(d=throat_d, h=throat_len+1);
        translate([0,0,-throat_len-mixtube_len-0.5]) cylinder(d=mixtube_d, h=mixtube_len+1);
        translate([0,0,-throat_len-mixtube_len-8.6]) cylinder(d=spout_d, h=9);
        // TANGENTIAL inlet: offset from centre so flow enters along the wall
        translate([0,0,cone_h-inlet_h_below_rim]) rotate([0,90,0])
            translate([0, cone_top_d/2-6, -2]) cylinder(d=inlet_d, h=cone_top_d/2+18);
        if (half_section) translate([0,-100,-120]) cube([200,200,300]);
    }
}

module vapor_shield() {
    // Separately molded drop-in ring: keeps the powder drop path dry.
    // Powder falls through the centre tube; steam rising off the swirl film
    // condenses on the shield's underside and drips back at the drip edge —
    // never onto the powder chute. Clearance gap tuned at prototype.
    color("SlateGray") translate([0,0,cone_h-2 + ex*40]) difference() {
        union() {
            cylinder(d=powder_tube_d+2*wall+2*shield_gap+8, h=3);          // cap disc
            translate([0,0,-9]) cylinder(d=powder_tube_d+2*wall, h=12);    // chute tube
            translate([0,0,-9]) cylinder(d1=powder_tube_d+2*wall+6,
                                         d2=powder_tube_d+2*wall, h=4);    // drip edge
        }
        translate([0,0,-10]) cylinder(d=powder_tube_d, h=15);              // dry chute
        if (half_section) translate([0,-100,-50]) cube([200,200,100]);
    }
}

color("MediumAquamarine", 0.85) manifold_body();
vapor_shield();

// ============================================================================
// PROTOTYPE TEST PLAN (bench rig ~$600 + the metering rig)
//  Rig: aquarium-grade pump + inline 300 W heater (bench substitute) + flow
//  meter feeding the tangential inlet; metering rig from cartridge bench
//  drops powder through the vapor shield. Print in CLEAR SLA.
//  Measure:
//   1. FILM COVERAGE: dye pulse — full wet wall within 1 s of flow start?
//   2. DISSOLUTION: 5 g creatine & greens into 250 mL @ 60 °C and 20 °C —
//      residue filter-dry-weigh: <1% undissolved, no wall cake after 20
//      servings without cleaning.
//   3. STEAM TEST: 95 °C water 30 s, then powder drop — chute must stay dry
//      (paper indicator in chute).
//   4. CARRYOVER: dispense flavor A, rinse 20 mL, dispense into clean water,
//      measure A (taste + refractometer) — target below taste threshold.
//   5. DRIP: after valve close, ≤2 drops from spout.
//  Iterate: throat_d (5–9), cone_angle (50–65), inlet_d (4.5–6), then lock.
// ============================================================================

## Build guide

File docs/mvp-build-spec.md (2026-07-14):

# Neuro-Stream — MVP Build Spec

**Goal:** a bench machine that proves the four make-or-break claims — ±2%
dosing, smart-cartridge docking, ±2 °F water, in-stream dissolution — built
from this document, the two schematics, and the printed parts.

**Companion diagrams:**
[`diagrams/mvp-wiring.svg`](diagrams/mvp-wiring.svg) ·
[`diagrams/mvp-plumbing.svg`](diagrams/mvp-plumbing.svg)
**Printed parts:** from [`../cad/cartridge-metering.scad`](../cad/cartridge-metering.scad)
and [`../cad/venturi-manifold.scad`](../cad/venturi-manifold.scad)
**Test matrix:** [`design-metering-venturi.md`](design-metering-venturi.md) §4

**MVP scope (deliberately smaller than the product):** ONE dispense station.
Cartridges are swapped by hand instead of a motorized carousel (the carousel is
proven engineering — rotation is not a risk worth prototyping). Everything else
is the real architecture.

---

## 1. Shopping list (~$700 electronics/hardware + ~$450 printed parts)

### Electronics

| Item | Example part | Qty | ~Cost |
|---|---|---|---|
| ESP32-S3 devkit | ESP32-S3-DevKitC-1-N8R2 | 1 | $15 |
| Stepper driver | BIGTREETECH TMC2209 v1.3 | 2 | $18 |
| Drive motor | NEMA17 + 5.18:1 planetary (StepperOnline 17HS15-1684S-PG5) | 1 | $35 |
| Carousel motor (optional) | NEMA17 pancake | 1 | $14 |
| Load cell + ADC | 1 kg TAL221 + SparkFun HX717 (or HX711) | 1 | $18 |
| NFC reader | PN532 module (set to I²C) + NTAG215 stickers ×10 | 1 | $16 |
| Flow meter | YF-S402B (G1/4, hall pulse) | 1 | $9 |
| NTC thermistors | 100 kΩ 1% glass bead, ×3 | 3 | $6 |
| SSR | 25 A zero-cross (Crydom-class, with heatsink) — genuine, not clone | 1 | $35 |
| Thermal cutoffs | KSD301 95 °C manual-reset + 130 °C one-shot fuse | 2 | $6 |
| PSU | Mean Well LRS-75-12 (12 V 6 A, enclosed) | 1 | $22 |
| Buck converter | 12→5 V 3 A module | 1 | $6 |
| MOSFET + flyback diode | IRLZ44N + 1N5822 (pump switch) | 1 | $3 |
| Touchscreen (optional on bench) | 2.8" ILI9341 SPI + touch | 1 | $12 |
| Hall switch + magnet, reed switch | dock-aligned + manifold-present interlocks | 2 | $5 |
| GFCI adapter, IEC inlet w/ fuse, earthed metal project box for mains | — | — | $45 |
| Wire, JST connectors, perfboard, standoffs | — | — | $30 |

### Water path

| Item | Spec | ~Cost |
|---|---|---|
| Pump | 12 V diaphragm, potable-rated, 0.5–1 L/min (e.g., Bartendro/Flojet-class) | $25 |
| Inline heater | 1200 W thick-film coffee-machine heater, 316L wetted (or **skip for cold-water phase 1**) | $40 |
| Silicone tube | platinum-cured, 8 mm OD × 5 mm ID, 2 m | $15 |
| Barbs, tees, clamps | PP or 304 SS, 8 mm | $20 |
| Check valve | 8 mm inline, silicone/PP | $5 |
| Tank | any 2 L food container, bulkhead fitting at bottom | $12 |

### Printed / fabricated (upload STLs to a service like Craftcloud/Xometry)

| Part | File / module | Process | Qty | ~Cost |
|---|---|---|---|---|
| Powder cartridge housing | `cartridge-metering.scad` part="powder" housing | **Clear SLA** (watch powder move) | 3 | $90 |
| Powder screw + agitator | same, screw | **MJF PA12** or machined POM | 3+3 | $120 |
| Syrup pump housing + piston + leadscrew | part="syrup" | MJF PA12 / machined POM | 2 sets | $110 |
| Mixing cone + vapor shield | `venturi-manifold.scad` | **Clear SLA**, 3 throat variants (Ø5/7/9) | 3+1 | $80 |
| Dock frame, motor mount, cartridge collar | simple brackets — any FDM printer | — | ~$30 |
| Duckbill/umbrella valves, Ø20 X-ring | **buy silicone** (Minivalve or eBay assortment) — don't print seals | — | $25 |

## 2. Wiring — pin map (matches the schematic)

| ESP32-S3 pin | Connects to | Notes |
|---|---|---|
| GPIO4 / GPIO5 | TMC2209 #1 STEP / DIR | drive motor |
| GPIO15 / GPIO16 | TMC2209 #2 STEP / DIR | carousel (optional) |
| GPIO6 | both TMC2209 EN | active low |
| GPIO7 | both TMC2209 UART (addr 0 / 1) | 1 kΩ into PDN_UART |
| GPIO13 | SSR control + | SSR − to GND; **series with GPIO21 watchdog gate** |
| GPIO21 | 555/monostable hardware watchdog | firmware strokes it at 2 Hz; loss = SSR off |
| GPIO14 | IRLZ44N gate (pump) | 100 Ω series, 100 k pulldown, diode across pump |
| GPIO12 | flow meter signal | 10 k pull-up to 3.3 V |
| GPIO1 / GPIO2 | NTC dividers (spout / heater body) | 100 k NTC + 100 k 1% to 3.3 V |
| GPIO10 / GPIO11 | HX717 DOUT / SCK | load cell E±, S± per module silk |
| GPIO8 / GPIO9 | PN532 SDA / SCL | module DIP switches → I²C |
| GPIO17 / GPIO18 | dock hall switch / manifold reed switch | interlocks, pull-ups |
| SPI2 (GPIO33–38) | display SCK/MOSI/CS/DC/RST/BL | optional |
| 5 V / GND | from buck converter | common ground everywhere **except** mains side |

## 3. Assembly order (a competent maker: ~2 weekends)

1. **Frame:** 2020 aluminum extrusion or plywood tower. Cartridge dock collar
   at top (cartridge hangs neck-down), drive motor **below** it pointing up,
   its shaft carrying a printed 6-lobe spline (from the .scad) that engages
   the cartridge when you seat it. Mixing cone clamps 10–15 mm below the
   cartridge outlet. Glass sits on the load cell at the bottom.
2. **Dry dosing first (no water at all):** wire ESP32 + TMC2209 + load cell.
   Fill a powder cartridge with table salt or creatine. Run the dose test:
   command revolutions → weigh what falls into a cup on the load cell,
   cross-check on a 0.001 g balance. **This alone proves claim #1.**
3. **Cold water loop:** add tank → pump → flow meter → (tube where heater will
   go) → mixing cone. Verify the swirl film with food dye, then run
   dissolution tests cold. Proves claim #4 at room temperature.
4. **NFC:** stick NTAG215 tags on cartridges; write ingredient ID + a
   calibration constant from step 2's data; firmware reads tag before dosing.
   Proves claim #2.
5. **Heat — last, and only with the safety chain complete:** GFCI + earthed
   mains box + both thermal cutoffs + SSR + watchdog gate + boil-dry guard in
   firmware. PID + feed-forward per Phase 3 §3.3. Thermocouple reference at
   the spout. Proves claim #3.
   *If mains work isn't your comfort zone: hire any appliance tech for a day,
   or run the entire MVP cold — 3 of 4 claims need no heat.*

## 4. Firmware starting points

- Framework: ESP-IDF or Arduino-ESP32; libraries: `TMCStepper`, `HX711`
  (HX717-compatible), `Adafruit_PN532`, `LVGL` (if screen).
- Control loop 100 Hz: read flow + NTCs → PID/feed-forward (Phase 3 §3.3) →
  SSR burst duty; stroke watchdog at 2 Hz.
- Dose sequence exactly as Phase 3 §3.1–3.2 (cup check → tag verify →
  co-dispense → suck-back → verify weight).
- Log every dispense to flash/serial CSV: commanded g, revs, load-cell delta,
  water temp — this CSV **is** the evidence file for the test matrix.

## 5. What "done" looks like

The MVP passes when the `design-metering-venturi.md` §4 table is green:
dose σ ≤ 0.8%, full-to-empty drift flat within ±2%, syrup re-prime ≤ 7 s,
wet-wall coverage < 1 s, dissolution residue < 1%, spout ±2 °F. Bring those
CSVs to the Phase-5 beta gate — they're what you show engineers, co-packers,
and investors next.

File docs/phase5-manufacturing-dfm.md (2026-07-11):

# Neuro-Stream — Phase 5: Manufacturing Plan & Tiered Pricing (DFM)

**Status:** Draft for founder sign-off
**Date:** 2026-07-09
**Configuration priced:** 11-slot carousel machine (10 ingredients + cleaning
slot), water/heating/venturi system, touchscreen, per signed-off Phases 1–4.

---

## 1. How each part gets made (DFM review)

### Machine — 11-slot countertop unit

| Part | Process | Tooling cost (Asia) | Notes |
|---|---|---|---|
| Chassis skirt + tower (2 shells) | Injection mold, ABS | $45–60k × 2 | Biggest tools in the program |
| Carousel ring w/ molded gear | Injection mold, GF-PP | $28k | Ø~47 cm part — needs a large press (≥650 T); fewer vendors, quote early |
| Docking cone | Injection mold, GF-PP | $12k | |
| Water tank (2 pcs + lid) | Injection mold, Tritan | $30k | Clear part: high-polish tool |
| Venturi manifold + spout | Injection mold, Tritan | $16k | Food-contact, high-polish |
| Weigh platform, drip tray, small covers | Injection mold | $22k | Family tool |
| Machine lid | Injection mold, clear PC | $20k | |
| Internal deck plate | Sheet metal, 1.5 mm | $3k (soft tool) | Convert to molding later if volume grows |
| Drive spline shaft | CNC, 316L stainless | — | ~$3.80/pc machined; the one precision metal part |
| Motors, pump, heater, load cell, slew bearing, display, NFC, PCBA | Off-the-shelf / standard PCBA | — | See Phase 3 BOM |
| **Machine tooling total** | | **≈ $180–225k** | One-time, before first sellable unit |

### Cartridges (3 SKUs: powder, syrup, cleaning)

| Part set | Tooling | Notes |
|---|---|---|
| Shell + neck + base cap (shared across SKUs) | $38k (multi-cavity) | Shared geometry is the money-saver |
| Powder screw + agitator | $20k | POM, single tool |
| Syrup piston block + leadscrew | $26k | POM |
| LSR seals/valves (all SKUs) | $24k (2 micro-molds) | |
| Cleaning cartridge divider insert | $9k | Reuses shell |
| Aseptic bag + valve | — | Bought from bag-in-box supplier; MOQ ~50k bags |
| **Cartridge tooling total** | | **≈ $117k** |

**Program tooling total: ≈ $300–340k** (Asia; roughly 1.7–2× if tooled in the
US). This is the capital gate identified back in Phase 1 — unchanged.

## 2. Tiered pricing — machine cost at three year-1 volumes

Build cost per machine (parts + assembly + test + packaging, ex-factory):

| | **2,000 units** | **5,000 units** | **10,000 units** |
|---|---|---|---|
| Electronics + electromech (Phase 3 set) | $95 | $83 | $75 |
| Moldings (chassis, carousel, tank, etc.) | $46 | $38 | $33 |
| Hardware, bearing, spline, fasteners | $14 | $12 | $10 |
| Assembly + test labor | $22 | $16 | $13 |
| Packaging (retail box, foam, manual) | $11 | $9 | $8 |
| **Build cost (BOM + labor)** | **≈ $188** | **≈ $158** | **≈ $139** |
| + freight, duty, warranty reserve (~12%) | ≈ $211 | ≈ $177 | ≈ $156 |
| **Suggested retail (≈3× landed)** | **$599–649** | **$499–549** | **$449–479** |
| Tooling amortized per unit (if you prefer to load it) | +$160 | +$64 | +$32 |

Plain-English read: **at 2,000 units the machine wants to retail near $600;
at 10,000 it can hit $449.** The single biggest lever is volume on the molded
parts and electronics. (These are estimate-grade numbers, ±15%, for deciding
strategy — real quotes come from the CMs below.)

### 2.1 Small-batch costing (100–1,500 units) — a different world

Below ~2,000 units, steel injection molds ($300k+) make no financial sense.
Small batches are built a different way, and the per-machine price reflects it:

- **100–500 units:** enclosure and large plastics are **3D-printed (industrial
  MJF/SLS) or CNC-machined**, assembled by hand, mostly domestically. No big
  tooling bill — but each machine costs several times more to build.
- **500–1,500 units:** **"soft" aluminum molds** (cheaper, slower, wear out
  after ~10–50k parts) for the big plastics: ~40% of the steel-tool price,
  higher per-part cost.
- **Cartridges are the exception at every volume:** food-contact parts cannot
  be 3D printed to spec, so the cartridge needs real (soft) molds from day
  one: **~$50–65k minimum**, unavoidable even for a 100-unit pilot.

| Units built | How it's built | Build cost per machine | One-time costs (tools, fixtures) | What this run is for |
|---|---|---|---|---|
| **100** | 3D print + CNC, hand-built | ≈ $1,250 | ≈ $95k (cartridge soft molds + fixtures) | Beta/pilot program — do NOT retail; field-test with real users |
| **200** | same | ≈ $1,000 | ≈ $95k | Extended beta, press/investor units |
| **500** | soft molds for big parts | ≈ $430 | ≈ $150k | First sellable run, early-adopter pricing |
| **750** | soft molds | ≈ $385 | ≈ $150k | |
| **1,000** | soft molds | ≈ $345 | ≈ $155k | Realistic retail ~$799–899, or ~$699 at thin margin |
| **1,500** | soft molds, partial line assembly | ≈ $300 | ≈ $160k | Bridge run while steel tools are cut |
| *2,000+* | *steel molds (see table above)* | *$188 →* | *$300–340k* | *Real production economics begin* |

Plain-English read:

- **100–200 machines is a beta program, not a business.** At ~$1,000+ each
  plus ~$95k in setup, these units exist to prove the product with real users
  before you spend mold money. Standard playbook: build 100–200, learn,
  *then* commit tooling. Skipping certification is allowed only if units are
  loaned, not sold.
- **500–1,500 is the "early adopter" zone:** sellable, but the machine must
  retail at $699–899 to not lose money, and safety certification (~$35–55k)
  now applies in full — it doesn't shrink with volume, so at 500 units it
  alone adds ~$90 per machine.
- The smart sequence most hardware companies use: **150-unit beta (printed) →
  1,000–1,500 bridge run (soft molds) → steel tooling once demand is proven.**
  The soft molds aren't wasted money — they carry you while the steel tools
  are cut, and the cartridge soft molds are needed at every volume anyway.

### 2.2 MVP cost (before any of the above)

An MVP here means: **a machine that proves the four risky claims** — doses
within ±2%, docks/reads smart cartridges, hits temperature within ±2 °F, and
dissolves powder in-stream — in front of you, users, and investors. It does
not need to be pretty, certified, or food-safe yet.

| Stage | What it is | What it costs |
|---|---|---|
| **Bench MVP** (1 unit) | Ugly but working: 3D-printed frame and cartridges, off-the-shelf pump/heater/motors, dev-board electronics, basic touchscreen UI. Proves dosing, heating, mixing, docking on a bench. | **$15–25k** in parts/fabrication + engineering labor below |
| **Engineering labor for bench MVP** | 1 mechanical + 1 firmware engineer, ~3–4 months (contract) — or ~$0 if you have technical co-founders | **$40–80k** contracted; $0–20k with sweat equity |
| **Looks-like / works-like prototypes** (3–5 units) | Real enclosure finish, integrated PCB (not dev boards), app demo. What you show retailers and investors, and what the safety lab pre-reviews. | **$60–110k** including design labor |
| **Realistic total: idea → demonstrable MVP** | | **≈ $55–105k** (bench only) / **≈ $130–210k** (through polished prototypes) |

Sequence with the tiers above: **MVP ($55–105k) → 150-unit beta (~$220k) →
1,000–1,500 soft-mold bridge run → steel tooling at 5k+.** Each stage is a
go/no-go gate before the next check is written.

### Cartridge cost (the recurring item)

| Per filled-ready empty cartridge | 50k/yr | 250k/yr | 500k/yr |
|---|---|---|---|
| Powder cartridge | $1.65 | $1.25 | $1.05 |
| Syrup cartridge (incl. aseptic bag) | $2.40 | $1.85 | $1.60 |
| Cleaning cartridge | $2.10 | $1.70 | $1.50 |

(Formula, filling, and co-packer margin add on top — typically $1.50–4.00
depending on ingredients. A $20–30 subscription price holds healthy margin.)

## 3. Who builds it

| Volume | Right manufacturing partner |
|---|---|
| 2,000 | A small-appliance contract manufacturer in Shenzhen/Dongguan/Zhuhai that already builds coffee/espresso machines (they know heaters, pumps, UL). Found and vetted through an NPI (new-product-introduction) firm — e.g., Dragon Innovation-style consultancies — rather than cold-calling. |
| 5,000–10,000 | Same class of CM, now with dedicated line time; second-source the cartridge molding separately (cartridges are pure high-volume molding — any good molder can run them; keep them out of the machine CM's scope for cost control). |
| Cartridge filling | A **21 CFR 111-registered supplement co-packer** with powder-fill and liquid aseptic lines (Phase 4 decision). The novel step — writing each lot's calibration number to the smart tag on the fill line — is a check-weigher + tag-writer station your engineers install at the co-packer (~$60–90k one-time). |

## 4. Highest-risk items for cost overrun or delay (watch these)

1. **UL testing of the heater system** — strictest timeline item: 3–4 months
   and any failure means re-spin + re-test. Mitigate: use a pre-certified
   heater module and engage the lab before tooling.
2. **The Ø47 cm carousel molding** — large-press parts have fewer supplier
   options and longer tool debug. Mitigate: quote 3 vendors now; design allows
   splitting into 2 bonded halves if needed.
3. **Aseptic bag supplier MOQ (~50k)** — fine at scale, heavy for first runs.
   Mitigate: launch flavors share one bag size.
4. **2.8" touchscreen supply** — display modules go end-of-life fast.
   Mitigate: qualify two interchangeable panels at design time.
5. **Tooling capital timing (~$300–340k)** — all spent before revenue.
   Mitigate: stage it — machine tools first, cleaning-cartridge insert tool
   can trail by a quarter (manual cleaning instructions as stopgap).
6. **Co-packer calibration station** — custom equipment, single point of
   failure for the ±2% accuracy promise. Mitigate: build two stations; the
   second doubles as your QA lab unit.

---

**✅ WHAT I NEED FROM YOU (simple version):**

1. **Pick a year-1 volume plan.** 2,000 (safest cash, ~$599 retail),
   5,000 (~$499–549 retail), or 10,000 (~$449–479 retail, biggest bet).
   This decides which factories we talk to and locks the target price.
2. **OK the tooling budget** — about $300–340k one-time to make all the
   molds, before the first machine is sold.
3. **OK the partner plan** — Chinese coffee-machine-class factory for the
   machine, separate molder for cartridges, licensed supplement co-packer
   for filling.
4. Then → Phase 6: the testing plan that proves the machine doses accurately
   and keeps formulas fresh, plus the full certification checklist.

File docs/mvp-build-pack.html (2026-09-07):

Neuro-Stream · Builder's document — hand to your engineer (or your weekend self)

# MVP Build Pack

Everything needed to build the bench prototype that proves the four risky claims: ±2% dosing, smart cartridges, ±2 °F water, and in-stream dissolving. One dispense station, hand-swapped cartridges, ~$1,150 in parts, about two weekends of assembly. Full details live in the repo: docs/mvp-build-spec.md.

~$1,150parts total

1dispense station

2weekends

4claims proven

## 01Electrical — every wire

Three voltage zones, color-coded. The mains zone (red) stays sealed in its own earthed metal box — and the whole heater section can be skipped at first: three of the four tests run on cold water.

## 02Plumbing — every tube

One line, five stops: tank → pump → flow meter → heater → mixing cone. All silicone tube, 8 mm OD. The single geometry that matters: the water inlet enters the cone off-center so the water spins.

## 03The cartridges — printed and sectioned

Print the housings in clear resin so you can watch the material move. The screw and pump parts print in nylon or machine from POM. Never print seals — buy silicone duckbill and umbrella valves.

Powder cartridge section

POWDER · hopper cone, sweeper arms, 3-turn dosing screw (~0.65 g/rev), duckbill outlet

Syrup cartridge section

LIQUID · leadscrew drives keyed piston (1.26 mL/rev), inlet umbrella + outlet duckbill valves

Both cartridges end in the same 6-lobe socket, so one motor spins either. An NFC sticker on each carries its ingredient name and its measured grams-per-turn — the machine reads it on contact and refuses to dispense from a tag it can't read.

## 04Build order — risk first

Frame + dry dosing (no water)Tower frame, motor below the hanging cartridge, glass on the load cell. Command turns, weigh powder. This alone proves the ±2% claim.

Cold water loopTank, pump, flow meter, mixing cone. Food-dye the water to see the swirl film, then run dissolution tests at room temperature.

Smart tagsNFC stickers on the cartridges; write each one's measured dose-per-turn; firmware reads before dosing.

Heat — last, safety chain firstGFCI, earthed mains box, two thermal cutoffs, relay, watchdog, boil-dry guard — then tune temperature control to ±2 °F. Not comfortable with mains wiring? Hire an appliance tech for a day, or stay cold — 3 of 4 claims need no heat.

## 05Pass / fail

Test | Pass means
Dose repeatability (50 doses × 3 sizes × 3 powders) | Spread ≤ 0.8% of dose
Full-to-empty drift | Every dose within ±2%, no trend
Thick-syrup refill between strokes | ≤ 7 seconds
Swirl film coverage (dye test) | Full wet wall under 1 second
Dissolution (5 g greens, 250 mL) | < 1% residue, no wall cake after 20 servings
Water temperature at spout | Within ±2 °F of set point

Every dispense logs a CSV row (commanded dose, turns, measured weight, temp). Those CSVs are the evidence you carry to the 150-unit beta gate — and to investors.

Shopping list with part numbers + full pin map: docs/mvp-build-spec.md · printable parts: cad/cartridge-metering.scad, cad/venturi-manifold.scad · mzb1028/neuro-stream

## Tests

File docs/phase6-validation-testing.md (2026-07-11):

# Neuro-Stream — Phase 6: Validation & Testing Plan

**Status:** Final phase — written for the approved path: MVP → 150-unit beta → scale
**Date:** 2026-07-10

Plain-English purpose: before anyone's health drink depends on this machine,
we prove three things — **it doses what it says, keeps ingredients good, and
is safe** — and we collect the paperwork stores and regulators ask for.

---

## 1. Dosing accuracy — proving ±2% from full cartridge to empty

**The claim being tested:** every serving is within ±2% of the target dose,
from the first serving of a new cartridge to the last one before empty, in
real kitchen conditions.

### 1.1 Bench protocol (runs on the MVP, repeats every design change)

1. Take 6 cartridges per SKU (powder + syrup + micro-dose later), from 2
   different production lots.
2. On a lab balance (0.001 g, calibrated), dispense the **smallest, middle,
   and largest allowed dose**, in rotation, until the cartridge is empty
   (~100–200 servings per cartridge).
3. Record every dose against the machine's own log (the machine believes vs.
   the balance knows).
4. **Pass:** ≥99% of doses within ±2%; no single dose beyond ±4%; no drift
   trend across cartridge life (regression slope statistically flat).
5. Repeat the whole matrix at: 15 °C/30 %RH, 25 °C/50 %RH, 32 °C/80 %RH
   (cold kitchen, normal kitchen, humid summer kitchen) — humidity is the
   powder killer, so it gets tested explicitly.
6. Repeat after the machine has run a 10,000-serving endurance cycle
   (motors/spline wear) and after 50 self-clean cycles (chemical exposure).

### 1.2 Temperature accuracy (±2 °F)

Thermocouple at the spout (not the machine's own sensor): 30 servings across
set-points 100–205 °F, three ambient temps, tank cold-start and warm.
**Pass:** 95% of servings within ±2 °F at the spout, all within ±3 °F.

### 1.3 What the 150 beta machines add (the real-world layer)

Every beta unit logs anonymized telemetry: dose commanded vs. load-cell
verified, StallGuard signatures, water hardness, cleaning compliance, faults.
150 kitchens × 12 weeks ≈ **>100,000 real servings** — this is the dataset
that catches what the lab can't (weird water, cold garages, curious kids,
never-cleaned units), and it becomes the accuracy-claim evidence file.

## 2. Formula stability — proving ingredients stay good inside the machine

**The claim:** an opened cartridge in the machine stays potent, safe, and
in-spec for its printed in-use life (target 60 days powder / 30 days liquid).

Per formula SKU (run by the co-packer's lab or a contract lab, ~$8–15k/SKU):

1. **Real-time in-device test:** cartridges installed in machines dispensing
   2 servings/day. Pull samples at day 0/7/14/30/45/60 and test:
   - **Potency:** active-ingredient assay ≥90% of label through end of life.
   - **Micro:** total plate count, yeast/mold, and for the preservative-free
     liquids a full **sterility hold** — the aseptic bag + one-way valve must
     show zero growth to end of life. This is the make-or-break test for the
     no-preservatives decision.
   - **Powder moisture:** Karl Fischer ≤5% throughout (validates the desiccant
     + wiper-seal design).
   - **Physical:** no caking/bridging (dose accuracy is re-checked on aged
     cartridges — stability and dosing tie together).
2. **Accelerated test (early warning):** same measurements at 40 °C/75 %RH
   for 4 weeks ≈ rough proxy for 3–4 months ambient. Run first, before
   betting real-time months on a formula.
3. **Cleaning-residue check:** after a self-clean cycle, swab + rinse-water
   assay for detergent/descaler residue at the spout. **Pass:** below
   food-code limits (this validates the triple-rinse firmware).
4. **Abuse cases:** cartridge left in a hot car (50 °C, 48 h) then used;
   machine unplugged 2 weeks mid-cartridge; tank water stagnant 1 week
   (micro test of first serving after). Each gets a defined pass or a
   firmware guard (e.g., stagnant-water auto-flush — already in spec).

## 3. Certificates & approvals needed before retail (the checklist)

| What | Who does it | Cost | When on your path |
|---|---|---|---|
| **Electrical safety (UL/ETL 60335-2-15)** — mandatory; it heats water | UL, Intertek, or TÜV lab | $25–40k, 3–4 mo | Start pre-review on the polished prototypes; formal cert on soft-mold units |
| **FCC (Wi-Fi/BLE)** | Test lab (uses the ESP32 module's existing cert) | $5–10k | Same time as UL |
| **FDA food-contact file** — proof every wetted material is food-legal | Regulatory consultant assembles supplier letters | $8–15k | Before cartridge molds are cut (letters gathered during sourcing) |
| **Supplement filling under 21 CFR 111 (cGMP)** | Your co-packer already holds it; you audit them | Audit ~$5k | Before first sellable cartridge |
| **Formula stability data (§2)** | Contract lab / co-packer lab | $8–15k per formula | Accelerated during beta; real-time before retail |
| **NSF/ANSI 42 water-path listing** — voluntary, retailers like it | NSF | $10–20k | After steel-tool units exist; not needed for beta/early-adopter sales |
| **CA Prop 65 review** | Same regulatory consultant | ~$3k | With the FDA file |
| **Wellness-claims legal review** — app suggestions stay "wellness," not medical | Healthcare/FDA attorney | $5–10k | Before the app ships wearable-driven suggestions |
| **Insurance (product liability)** | Broker | ~$15–30k/yr premium | Before any unit leaves your hands — including beta loaners |

**Total certification + validation budget through retail launch: ≈ $90–150k**
(consistent with the ~$35–55k Phase 4 core-cert figure plus stability
science, legal, and NSF).

### What each stage of your path must clear before the next

- **MVP → beta:** §1.1 bench dosing pass + §1.2 temperature pass + §2
  accelerated stability pass on launch formulas + basic electrical safety
  pre-review (lab looks at the design before you build 150 of anything).
- **Beta → soft-mold sales run:** beta telemetry confirms ±2% in the field;
  UL/ETL formal testing underway; FDA materials file complete; co-packer
  audited; insurance active.
- **Sales run → steel-tool scale:** UL/ETL granted; real-time stability
  complete on all shipping formulas; NSF listing filed; claims legal review
  done.

---

## Program status: ALL SIX PHASES DELIVERED

| Phase | Deliverable | Status |
|---|---|---|
| 1 — Concept & mechanism | Architecture B smart cartridges | ✅ signed off |
| 2 — Parametric CAD | `cad/neuro-stream.scad` + renders | ✅ signed off (11 slots, water system) |
| 3 — Electronics & firmware | ESP32-S3, ±2 °F control, error matrix | ✅ signed off (+connected-product amendments) |
| 4 — Materials & food safety | 21 CFR 177 sourcing spec, self-clean model | ✅ signed off |
| 5 — Manufacturing & pricing | DFM, tooling, tiers from MVP to 10k units | ✅ signed off (path a: MVP → beta → scale) |
| 6 — Validation & testing | This document | ✅ signed off |

**✅ APPROVED by founder 2026-07-10. All six phases signed off — the
engineering program is complete and this repository is the handoff package.**

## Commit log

2026-07-09 Phase 2: parametric OpenSCAD model, renders, and CAD documentation
    Carousel-layout countertop unit with smart-cartridge docking; Phase 1 doc
    updated with founder sign-off amendments (preservative-free liquids via
    sterile-fill aseptic bags, 4-ingredient recipes).
    Claude-Session: https://claude.ai/code/session_01JN7ujuQEfeUcp3xVb83dgP
    [neuro-stream.scad]
2026-07-09 Fix render path (cad/cad -> cad/renders)
    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
2026-07-09 Fold water/heating/venturi-mixing subsystem into model and docs; add Phase 3 electronics & firmware spec
    Central in-carousel water tank, pump/heater path, venturi manifold replacing
    the drop funnel. Phase 3: ESP32-S3 architecture, dose/thermal control
    firmware design (feed-forward + PID for +/-2F), error matrix, electronics BOM.
    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
    [neuro-stream.scad]
2026-07-09 Phase 3 sign-off amendments (connected product, offline-first) and Phase 4 materials & food-safety spec; 303->316L spline correction
    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
    [neuro-stream.scad]
2026-07-11 11-slot configuration, self-cleaning model (Phase 4 amendment), Phase 5 manufacturing plan with tiered pricing
    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
    [neuro-stream.scad]
2026-07-11 Phase 5: add MVP costing stage
    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
2026-07-11 Phase 4 final sign-off recorded; Phase 6 validation & testing plan (dosing, stability, certification checklist, stage gates)
    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
2026-07-11 Deep design: cartridge metering internals and wet-wall swirl manifold, prototype-ready models + bench test plan
    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
    [cartridge-metering.scad, venturi-manifold.scad]
2026-07-11 Exterior detailing: hinged lid (lid_open param), front touchscreen; exterior/open/dispenser/base-internals renders
    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
    [neuro-stream.scad]
2026-07-14 MVP build pack: wiring + plumbing schematics, cartridge section renders, build spec with shopping list and pin map
    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
